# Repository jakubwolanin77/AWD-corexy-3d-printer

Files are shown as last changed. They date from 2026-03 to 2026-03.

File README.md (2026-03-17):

# CoreXY 3D Printer — Engineering Thesis Project






> Engineering Bachelor's Thesis — Jakub Wolanin, 2026  
> Institute of Technology, Automation & Robotics — Industrial Automation  

## 📖 Overview

This repository contains the complete engineering documentation and source files for a custom-built high-speed CoreXY 3D printer designed from scratch. The project covers the full engineering process — from mechanical design verified by FEM simulation, through electrical system integration, to advanced firmware configuration and AI-assisted print monitoring.

The printer is built on open-source solutions (Klipper, Mainsail, Moonraker)



## ✨ Key Features

| Feature | Details |
|---|---|
| 🏗️ Kinematics | CoreXY with 4-motor AWD (All-Wheel Drive) — doubled torque & belt stability |
| 📐 Build Volume | 300 × 265 × 270 mm (X × Y × Z) *(see known issues — belt path limits full 310×310 bed usage)* |
| ⚙️ Frame | 2020 aluminum V-slot profiles — FEM-verified (FreeCAD CalculiX) |
| 🔧 Linear Motion | MGN15 linear rails on all axes |
| 🎯 Auto Leveling | Z-Tilt with KlickyNG magnetic probe — 0.0075 mm accuracy |
| 📳 Resonance Comp. | Input Shaper (ADXL345 accelerometer) — eliminates ringing artifacts |
| 🤖 AI Monitoring |Octoeverywhere — real-time failure detection via camera |
| 📡 Remote Access | Mainsail web UI + ZeroTier Mesh VPN — worldwide monitoring |
| 🔔 Notification* | Discord alerts on print failures |
| 💻 Firmware | [Klipper](https://www.klipper3d.org/) on Raspberry Pi 4 + BTT Octopus Pro |

## 🔬 Mechanical Design Highlights

### Frame — FEM Analysis (FreeCAD + CalculiX)
The frame (530×530×620 mm, 2020 Al profiles) was verified with modal FEM analysis:

| Profile | Resonance freq. Y-axis | Resonance freq. X-axis |
|---|---|---|
| 2020 Al | 33.4 Hz | 35.6 Hz |
FEM modal analysis of the frame X axis
FEM modal analysis of the frame Y axis

**verification via input shaper**
input shaper results X axis
input shaper results Y axis

 Belt System
- GT2 9mm wide belts 
- Fiberglass-reinforced core 
- Non-crossed belt layout — reduced mechanical wear
- Optimal tension range: 45–55 Hz (calculated from string vibration model)

### Printhead: Dragon Burner V8
- Mounted on MGN15 rail ( too heavy, MGN9H should have been used)
- Phaetus Dragon HF hotend (High Flow)
- Sherpa Mini direct drive extruder
- Dual-fan part cooling optimized for high flow rates
- KlickyNG used as probe
---

## ⚠️ Known Issues — Hardware Revision in Progress

The current prototype revealed two mechanical design flaws that are actively being addressed:

### 1. Incorrect Motor Mount & Front-Right Idler Misalignment
- **Issue:** The front-right motor bracket is too weak causing ringing of the belt idler roller. This introduces asymmetric belt tension between the two CoreXY loops.
- **Effect:** Increased ringing artifacts on one print axis that cannot be fully compensated by Input Shaper alone.
- **Status:** 🔧 Redesigning the motor mount bracket — corrected version being modeled in FreeCAD.

### 2. Gantry Mass — Speed Limitation

Gantry

- **Issue:** The current gantry (Dragon Burner V8 toolhead + mounting hardware + dual belts) exceeds the target mass budget, limiting achievable accelerations without introducing resonance beyond the Input Shaper's compensation range.
- **Effect:** Maximum practical print speed is below the original design target.
- **Status:** 🔧 Investigating lighter mounting hardware( carbon fiber square tube + MGN9H linear rail) and alternative toolhead configurations to reduce moving mass.

### 3. XY Axis Design — Reduced Effective Build Volume
- **Issue:** The current XY belt routing geometry places the belt path in a way that physically interferes with the printhead's range of motion on one side. The physical bed is 310×310 mm, but the usable print area is limited to **300×265 mm** because the belt blocks the toolhead from reaching the full bed surface.
- **Effect:** ~15% of the heated bed area is inaccessible — wasted heating energy and reduced print area.
- **Status:** 🔧 XY belt routing needs to be redesigned with additional clearance; corrected idler positions being evaluated.

### 4. Heated Bed — Insufficient Power & Slow Heat-Up
- **Issue:** The installed heated bed has insufficient wattage for the 310×310 mm surface area, resulting in very slow heat-up times and difficulty maintaining uniform temperature across the bed, especially at corners.
- **Effect:** Long wait times before printing; possible temperature gradients causing adhesion issues near bed edges.
- **Status:** 🔧 Evaluating higher-wattage bed heater or AC mains bed (via SSR relay) as a replacement.

### 5. Bed Z-Stability — 3-Point Mount Sagging (~0.2 mm First Layer Variation)

heightmap of the heated bed

- **Issue:** The heated bed is attached to the Z-axis using a 3-point mounting system. To adapt from the bed's 2-hole pattern to the 3-point lead screw layout, a bridge/adapter beam was used. This introduces structural flex — the bed sags between support points, causing a measurable height variation of approximately **0.2 mm** across the first layer, visible in bed mesh scans.
- **Effect:** First layer consistency is compromised; mesh compensation partially corrects this, but the flex remains a source of instability.
- **Status:** 🔧 A 4-point mounting design (direct attachment without adapter beam) is being developed to eliminate the flex and improve Z-plane rigidity.

> 📸 *Bed mesh scan photo documenting the Z variation will be added to the `assets/` directory.*

---

## 📁 Repository Structure

```
AWD-corexy-3d-printer/
├── README.md
├── LICENSE                              # GPL-3.0
│
├── CAD/                                 # Custom-designed components (STEP format)
│   ├── XY motor front right mounting.step
│   ├── XY motor front-left mounting.step
│   ├── XY motor rear-left mounting.step
│   ├── XY motor rear-right mounting.step
│   ├── Z motor left mounting.step
│   ├── Z motor rear mounting.step
│   ├── Z motor right mounting.step
│   ├── endstop X mounting.step
│   ├── gantry mounting left.step
│   ├── gantry mounting right.step
│   ├── heated bed mounting back.step
│   ├── heated bed mounting left.step
│   ├── heated bed mounting right.step
│   ├── klickyNG dock mounting.step
│   ├── printhead mounting1.step
│   └── printhead mounting2.step
│
├── conf files/                          # Real Klipper configuration files
│   ├── printer.cfg                      # Main Klipper config (BTT Octopus Pro, CoreXY AWD)
│   ├── mainsail.cfg                     # Mainsail UI configuration
│   ├── moonraker.conf.txt               # Moonraker API server config
│   ├── octoeverywhere.conf.txt          # OctoEverywhere remote access config
│   └── crowsnest.conf                   # Camera streaming config
│
└── documentation/                       # Engineering documentation & schematics
    ├── Jakub Wolanin-praca inż.pdf      # Full engineering thesis (Polish)
    ├── Załącznik 1 Schemat połączeń elektrycznych  # Wiring schematic
    ├── schemat sterowanie i komunikacja            # Control & communication diagram
    └── schemat zasilanie.png            # Power supply schematic
```

---

## 🚀 Quick Start — Klipper Config

All configuration files are in [`klipper_config/`](./klipper_config/).

> ⚠️ **Important:** Pin assignments in `printer.cfg` are specific to the **BTT Octopus Pro** board with the motor layout described in the thesis. Adjust per your hardware.

## 🛠️ Technologies Used

- **Firmware:** [Klipper](https://www.klipper3d.org/) + [Moonraker](https://github.com/Arksine/moonraker)
- **Printer Control (AI):** [OctoPrint](https://octoprint.org/)
- **Web UI:** [Mainsail](https://docs.mainsail.xyz/)
- **Camera:** Crowsnest stream server
- **VPN:** ZeroTier Mesh VPN
- **FEM Analysis:** FreeCAD + CalculiX solver
- **CAD:** FreeCAD
- **MCU:** BTT Octopus Pro (STM32F429)
- **Host:** Raspberry Pi 4

---

## 📜 License & Open-Source Credits

This project is released under the **[GPL-3.0 License](./LICENSE)**.

It builds upon the following open-source projects:

| Project | License | Repository |
|---|---|---|
| Klipper | GPL-3.0 | [github.com/Klipper3d/klipper](https://github.com/Klipper3d/klipper) |
| Moonraker | GPL-3.0 | [github.com/Arksine/moonraker](https://github.com/Arksine/moonraker) |
| Mainsail | GPL-3.0 | [github.com/mainsail-crew/mainsail](https://github.com/mainsail-crew/mainsail) |
| Dragon Burner V8 | GPL-3.0 | [github.com/chirpy2605/voron-user-mods](https://github.com/chirpy2605/voron-user-mods) |
| Sherpa Mini Extruder | GPL-3.0 | [github.com/Annex-Engineering/Sherpa_Mini-Extruder](https://github.com/Annex-Engineering/Sherpa_Mini-Extruder) |
| KlickyNG Probe | GPL-3.0 | [github.com/jlas1/Klicky-Probe](https://github.com/jlas1/Klicky-Probe) |
| OctoPrint | AGPL-3.0 | [github.com/OctoPrint/OctoPrint](https://github.com/OctoPrint/OctoPrint) |

All original design work, configuration, documentation and code in this repository is © 2026 Jakub Wolanin and licensed under GPL-3.0.

---

## 👤 Author

**Jakub Wolanin**  
Engineering thesis — Automation & Robotics, Industrial Automation specialization  
Krosno 2026
contact:
jakubwolanin77@gmail.com

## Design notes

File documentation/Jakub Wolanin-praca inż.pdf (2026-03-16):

INSTYTUT | Politechniczny
KIERUNEK: | Automatyka i Robotyka
KSZTAŁCENIE W ZAKRESIE: | Automatyka przemysłowa

## Jakub Wolanin

27111

## Projekt drukarki 3D

### Praca dyplomowa inżynierska napisana pod kierunkiem:

dr hab. inż., Tomasz
Korbiel

## Przyjmuję pracę: |

(data i podpis promotora)

## Krosno 2025

Spis Treści

### Spis treści

Załącznik nr 1 -Schemat połączeń elektrycznych systemu sterowania drukarką 3D ... 125

1.Wprowadzenie

### 1.1 Cel pracy

Celem niniejszej pracy inżynierskiej jest opracowanie kompletnej dokumentacji inżynierskiej i produkcyjnej drukarki 3D typu CoreXY.

Projekt obejmuje nie tylko założenia konstrukcyjne fizycznego urządzenia (ramy nośnej, układu napędowego), ale również – jako integralną część zadania inżynierskiego – dobór i wdrożenie zaawansowanych algorytmów sterowania w środowisku Klipper. Algorytmy te obejmują kompensację drgań Input Shaper oraz sterowanie wyprzedzające - Pressure Advance.

Cel pracy zostaje osiągnięty poprzez stworzenie projektu gotowego do wdrożenia (prototypowania). Fizyczna budowa i uruchomienie prototypu, opisane w dalszej części pracy, stanowią etap weryfikacyjny przyjętych założeń projektowych, potwierdzający poprawność przygotowanej dokumentacji.

### 1.2 Zakres i wymagania funkcjonalne projektu

Zakres niniejszego projektu obejmuje zaprojektowanie, wykonanie, kalibrację oraz

uruchomienie drukarki 3D typu CoreXY opartej na oprogramowaniu Klipper i

rozwiązaniach open-source. Urządzenie ma łączyć wysoką jakość wydruku z wysoką

prędkością.

Szczegółowy zakres projektu:

1. Analiza wstępna - przegląd istniejących rozwiązań w dziedzinie drukarek 3D

FDM oraz wybór odpowiedniej kinematyki jako podstawy konstrukcji

2. Projekt mechaniczny drukarki obejmujący:
- opracowanie konstrukcji ramy o wysokiej sztywności,
- zaprojektowanie układu napędowego dla osi X/Y/Z,
3. Projekt elektryczny drukarki obejmujący dobór oraz integrację komponentów

takich jak:

- płyta główna,
- silniki krokowe i sterowniki,
- czujniki,
- zasilacz,
- odpowiednie przewody.
4. Konfiguracja oprogramowania Klipper oraz kalibracja drukarki 3D

Wymagania funkcjonalne drukarki 3D:

Projektowana drukarka powinna spełniać następujące wymagania funkcjonalne:

- Konstrukcja pozwalająca na obszar roboczy minimum 300x265x280mm (X, Y,

Z).

- Sztywna rama zapewniająca minimalne drgania i odkształcenia
- Zastosowanie lekkiej, sztywnej głowicy pozwalającej na druk z dużymi

prędkościami.

- Automatyczne poziomowanie stołu roboczego (procedura Z-Tilt z sondą

KlickyNG)

- Kontrola temperatury stołu roboczego.

Kontrola temperatury głowicy.

- Czujnik obecności filamentu.
- Analiza drgań w celu eliminacji rezonansów (akcelerometr + Input Shaper).
- Kontrola chłodzenia wydruku.
- Możliwość druku wielu materiałów takich jak: PETG, PLA, TPU.
- Łatwość rozbudowy dzięki modularnej budowie.
- Wysoka powtarzalność i stabilność wydruków.
- Inspekcja procesu przy użyciu AI (model YOLOv8)
- Zdalne sterowanie i monitoring (interfejs Mainsail + VPN)

### 2. Teoria druku FFF

### 2.1 Podstawy technologii FFF

Technologia FFF (Fused Filament Fabrication) – to jedna z technologii wytwarzania przyrostowego, w której element powstaje poprzez warstwowe nakładanie uplastycznionego tworzywa termoplastycznego [2]. Materiał w postaci filamentu jest wprowadzany do podgrzewanej głowicy, gdzie zostaje stopiony i następnie wyciskany przez dyszę wzdłuż zaprogramowanej ścieżki. W ten sposób kolejne warstwy łączą się ze sobą, tworząc gotowy model

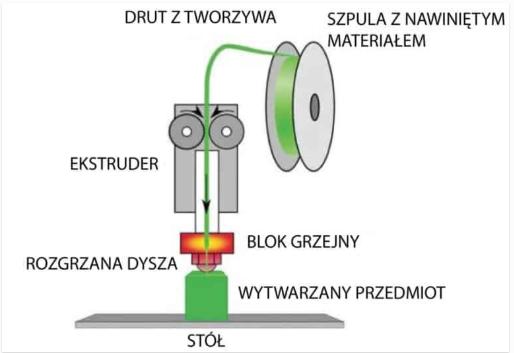
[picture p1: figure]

Rys. 1. Schemat procesu technologii FFF. Źródło: [1].

Technologia FFF ma pewne ograniczenia takie jak:
- widoczność linii warstw,
- trudność w druku nagłych zwisów (>55°)
- mniejsza dokładność wymiarowa niż w innych metodach druku 3D tj. SLA czy SLS, ze względu na kurczliwość materiału podczas chłodzenia

### 2.2 Parametry wpływające na jakość i prędkość druku

Ostateczna jakość i czas wydruku zależą od dużej liczby parametrów procesowych. Odpowiednie dobranie parametrów jest kluczowe dla uzyskania stabilności wymiarowej, wytrzymałości oraz jakości powierzchni wydruku.

Najważniejsze parametry wpływające na końcowy produkt:

Grubość warstwy
Mniejsza grubość warstwy poprawia adhezję warstw oraz jakość powierzchni wydruku. Jednocześnie znacząco wydłuża czas druku. Zwiększenie grubości warstwy pozwala skrócić czas wydruku kosztem jakości oraz adhezji warstw w osi Z.

Rys. 2. Porównanie czasu wydruku w zależności od grubości warstwy. Źródło: [4].

Rys. 3. Porównanie jakości powierzchni w zależności od grubości warstwy. Źródło: [4].

Temperatura dyszy
Temperatura wpływa na lepkość materiału oraz jakość łączenia warstw.

Zbyt niska temperatura powoduje:
- niedostateczne uplastycznienie filamentu,
- słabe sklejenie warstw,
- chropowatą powierzchnię,
- możliwe zatory,
- zwiększenie ryzyka pękania. Zbyt wysoka temperatura powoduje:
- zbytnie upłynnienie filamentu,
- rozmyte szczegóły,
- widoczne przebarwienia,
- zjawisko nitkowania.

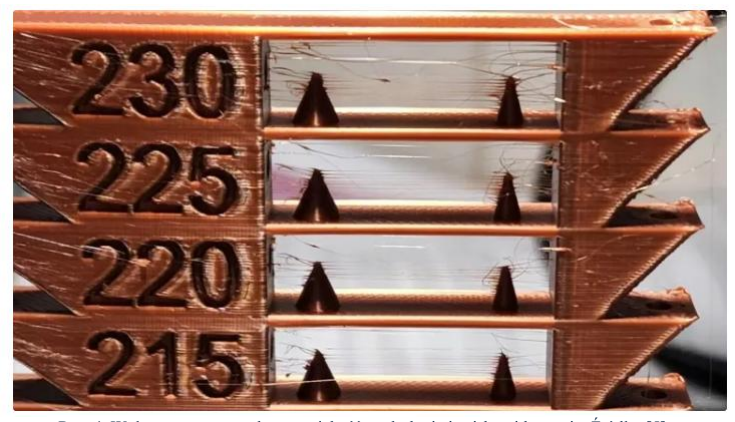
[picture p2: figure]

Rys. 4. Wpływ temperatury dyszy na jakość wydruku i zjawisko nitkowania. Źródło: [5].

Temperatura stołu
- Zbyt niska temperatura stołu powoduje słabe przywieranie modelu do stołu. Model może podwijać się w rogach oraz deformować ze względu na nierównomierne stygnięcie wydruku.
- Zbyt wysoka temperatura może prowadzić do wybrzuszeń lub pofalowania warstw z powodu nadmiernego rozszerzenia się filamentu.

Rys.5 Podwijanie się wydruku. Źródło: [6]

Chłodzenie
Prędkość wentylatora chłodzącego wydruk. Chłodzenie jest niezbędne do szybkiego utwardzania materiału, co pozwala na druk mostów i zwisów bez konieczności stosowania podpór na krótkich odcinkach. Przy wydruku z takich materiałów jak ABS chłodzenie musi być wyłączone. Gwałtowne utwardzenie materiału prowadzi do deformacji wydruku i osłabienia wiązań międzywarstwowych.

Prędkość druku
Zwiększenie prędkości znacząco skraca czas wydruku, jednak może pogorszyć jakość powierzchni i powodować gorsze połączenie warstw. Prędkość wydruku należy dobierać zależnie od konstrukcji drukarki oraz jej podzespołów. Sztywniejsza konstrukcja oraz większa przepustowość hotendu pozwalają uzyskać większe prędkości druku bez pogarszania jego jakości.

Liczba obrysów
Jest to liczba linii osadzanych na zewnątrz i wewnątrz ścian modelu. Oznacza to grubość solidnej ściany modelu. Większa liczba obrysów zwiększa sztywność i odporność na pękanie. Zwiększenie liczby obrysów wydłuża czas druku.

Rys. 6. Wpływ liczby obrysów na strukturę ściany modelu. Źródło: [7].

Projektując model w środowisku CAD, należy grubość cienkiej ścianki dobrać tak, aby obliczona przez slicer optymalna grubość odpowiadała założonej liczbie obrysów i wysokości warstwy. Pozwala to uzyskać najlepszą jakość powierzchni ścian, unikając nakładania się obrysów.
Przykładowo PrusaSlicer, do obliczania optymalnej grubości cienkiej ściany używa konkretnego wzoru.

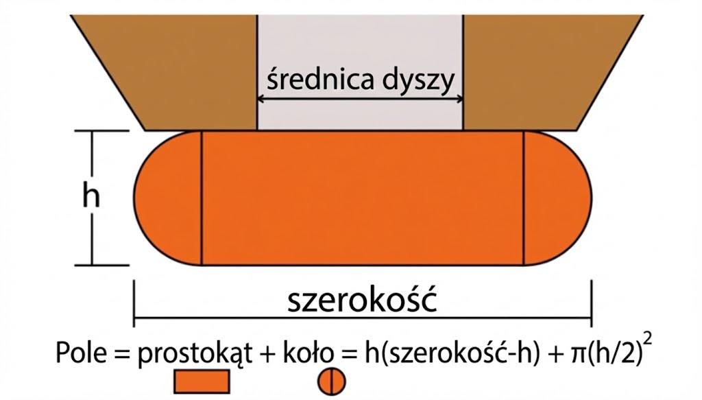
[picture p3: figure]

Rys. 7.Wzór obliczania optymalnej szerokości ścieżki (grubości ścianki). Źródło: [7].

Zwarte warstwy górne/dolne
Zwiększenie liczby warstw dolnych lub górnych zwiększa grubość podstawy lub powłoki górnej. Im większa liczba zwartych warstw, tym większa wytrzymałość oraz sztywność modelu. Zwiększenie liczby zwartych warstw wydłuża wydruk.

Rys. 8. Wpływ liczby górnych warstw na jakość zamknięcia powierzchni (od lewej: 1, 2, 3, 5 warstw). Źródło: [8].

Wypełnienie
Gęstość wewnętrznej struktury wypełniającej model, wyrażana w procentach. Im większa gęstość wypełnienia, tym większa wytrzymałość i waga modelu.

Rys. 9. Zależność między gęstością wypełnienia a parametrami wytrzymałościowymi i czasem druku.
Źródło: [8].

Wzór wypełnienia
Geometria siatki wypełnienia. Opcji wzoru siatki jest wiele i należy ją dobrać indywidualnie do danego modelu. Wzór siatki wpływa znacząco na wytrzymałość i czas wydruku.
Wybierając wzór typu Gyroid zapewniamy niemalże jednakową wytrzymałość we wszystkich kierunkach. Wybierając wzór typu Cubic najlepszą wytrzymałość uzyskamy wzdłuż osi Z.

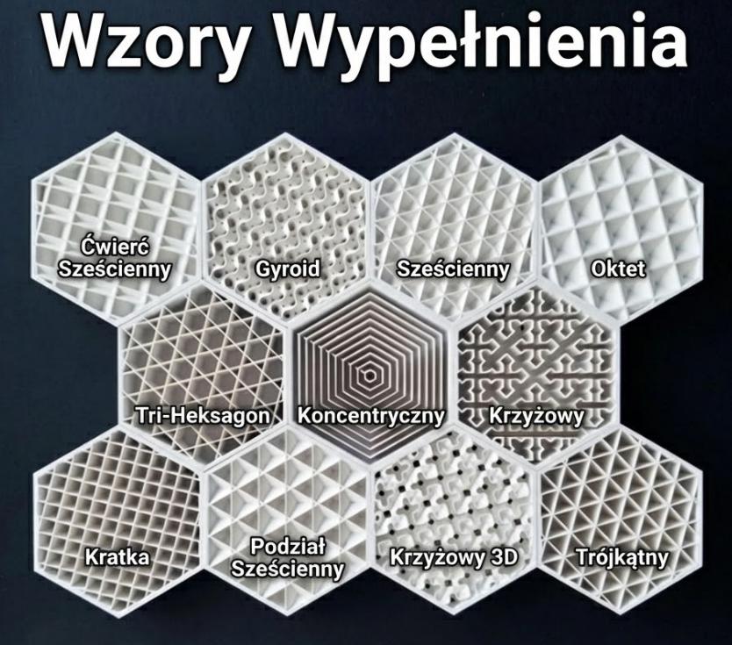
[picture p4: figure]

Rys. 10. Przykłady wzorów wypełnienia stosowanych w druku 3D. Źródło: [9].

Retrakcja
Szybkość oraz długość cofnięcia filamentu przez ekstruder w głowicy. Niepoprawnie skalibrowana retrakcja powoduje wyciekanie materiału z dyszy, czego skutkiem jest nitkowanie.

### 2.3 Typy kinematyki drukarek -porównanie

Kinematyka drukarki to sposób, w jaki ruch obrotowy silników przekłada się na ruch głowicy i stołu roboczego w przestrzeni trójwymiarowej [12]. Wybór architektury ma kluczowy wpływ na sztywność i precyzję drukarki 3D.

Kinematyka Kartezjańska:
Jest to najbardziej rozpowszechniony typ, szczególnie w tańszych i hobbystycznych drukarkach.
Zasada działania
- Oś X – porusza głowicą drukującą (lewo-prawo)
- Oś Y – porusza stołem roboczym (przód- tył)
- Oś Z- porusza osią X (góra-dół)

Rys. 11. Drukarka Creality Ender 3 S1 Pro jako przykład kinematyki kartezjańskiej ("Bedslinger"). Źródło:[34]

Zalety:
- Prostota konstrukcji
- Niska cena,
- niezależność ruchu osi ułatwia kalibrację i rozwiązywanie problemów.

Wady:
- Niska prędkość ograniczona ciężkim stołem roboczym.

Kinematyka CoreXY:
Architektura ta popularna jest w zaawansowanych konstrukcjach DIY oraz droższych drukarkach do zastosowań profesjonalnych.

Zasada działania:
- Oś Z: Stół porusza się tylko w pionie
- Oś X/Y: Głowica porusza w płaszczyźnie poziomej, napędzana przez układ dwóch lub czterech stacjonarnych silników i system pasków. Ruch w osi X wymaga zgodnego obrotu silników, a ruch w osi Y- przeciwbieżnego [12].

Rys. 12. Drukarka Sovol SV08 jako przykład kinematyki CoreXY. Źródło: [35].

Zalety:
- Większa sztywność całej konstrukcji
- Silniki pozostają nieruchome na ramie, co znacząco obniża masę głowicy
- Wyższa prędkość oraz przyspieszenie
Wady:
- Złożony układ pasków napędowych
- Wymaga precyzyjnego naciągnięcia i prowadzenia
- Błędy konstrukcyjne lub montażowe mają przełożenie na obie osie (X i Y)

Kinematyka Delta:
Konstrukcja typu Delta jest najrzadziej spotykanym typem kinematyki w komercyjnych drukarkach 3D, zazwyczaj dominuje ona w segmentach, w których liczy się szybkość i wysokość wydruku.

Zasada działania
Głowica zawieszona jest na 3 ramionach i poruszana przez 3 silniki umieszczone na górze ramy. Głowica porusza się w 3 osiach (X, Y, Z). Pozycja głowicy jest obliczana poprzez złożoną geometrię na podstawie długości ramion i ruchu silników.

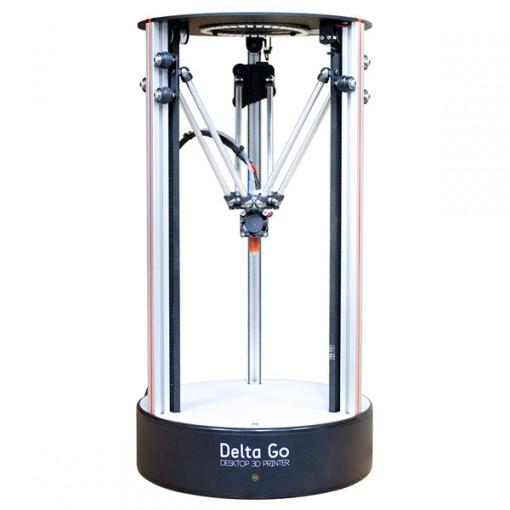
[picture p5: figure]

Rys. 13. Drukarka Deltaprintr Delta Go jako przykład kinematyki Delta. Źródło [36].

Zalety:
- Bardzo lekka głowica i nieruchomy stół pozwalają na uzyskanie bardzo dużych prędkości wydruku.
Wady:
- Sposób konstrukcji wymusza zastosowanie cylindrycznej przestrzeni roboczej, co znacznie ją pomniejsza w porównaniu do innych typów kinematyki
- Próbując powiększyć dostępną przestrzeń roboczą, zmuszeni jesteśmy wydłużać ramiona, które mogą wpadać w wibracje powodujące artefakty na końcowym wydruku

### 3. Projekt mechaniczny drukarki

### 3.1 Wprowadzenie

Konstrukcja mechaniczna jest kluczowym elementem budowy drukarki 3D. Wpływa zarówno na sposób działania urządzenia, jak i na możliwości jego modernizacji w przyszłości.

W przypadku drukarek wykorzystujących kinematykę CoreXY, szczególnie ważne jest skupienie się na sztywności ramy, dokładności prowadzenia osi oraz zachowaniu jak najmniejszej masy części ruchomych. Konstrukcja mechaniczna powinna zapewniać stabilność drukarki przy dużych prędkościach, redukować wibracje i umożliwiać dokładne odwzorowanie kształtu modelu.

### 3.2 Rama nośna

Geometria i materiał

Rys. 14. Projekt ramy drukarki CoreXY.

Legenda:
- 1-4 – Profile aluminiowe V-slot 2020 620mm
- 5 - Profil aluminiowy V-slot 2020 500mm
- 6-17 - Profile aluminiowe V-slot 2020 490mm

Główna rama drukarki to podstawa całego systemu CoreXY, zaprojektowana została jako prostopadłościan o wymiarach 530x530x620 wykonany z profili aluminiowych 2020.

Uzasadnienie wyboru materiału:
Wybór profilu 2020 został poprzedzony analizą alternatywnych rozwiązań z uwzględnieniem specyfiki systemu CoreXY [12]. System ten wymaga minimalizacji masy ruchomej i maksymalizacji sztywności ramy stałej w celu skutecznego tłumienia rezonansów przy dużych przyspieszeniach.

1 Rama spawana z profili stalowych - Zapewnia wysoką sztywność, jednak proces spawania wprowadza naprężenia cieplne i wymaga zachowania idealnej prostopadłości. Każda odchyłka trwale obniża jakość druku, a konstrukcja jest niemodyfikowalna.
2 Rama skręcana z profili aluminiowych V-slot - Modułowość pozwala na łatwe modyfikacje (np. powiększenie pola roboczego przez wymianę profili pionowych). Jest to standard w konstrukcjach amatorskich i półprofesjonalnych.

Dobór profilu ramy:

Tab.1. Porównanie parametrów profili aluminiowych V-slot. Źródło: [15], [16].
Parametr | Profil aluminiowy 2020 | Profil aluminiowy 3030
Moment bezwładności Ix | 6531,00 [mm⁴ ] | 26797,00 [mm⁴ ]
Waga nominalna | 0,429 [kg/m] | 0.835[kg/m]
Cena za 1mb | 22,66 [zł] | 42,10 [zł

W celu weryfikacji doboru profilu nośnego przeprowadzono obliczenia statycznego ugięcia belki dla zastosowanego profilu 2020 oraz alternatywnego profilu 3030.

Wzór na strzałkę ugięcia belki swobodnie podpartej:

f =

F ∗ L

3
48 ∗ E ∗ Ix

Wzór na strzałkę ugięcia belki obustronnie utwierdzonej:

f =

F ∗ L

3
192 ∗ E ∗ Ix

Do obliczeń przyjęto następujące wartości:
- Materiał: Aluminium 6063-T5 (Moduł Younga E = 69 GPa)
- Długość belki L = 490 mm
- Obciążenie punktowe F = 10.0 N (połowa masy całej osi bramowej)
- Moment bezwładności Ix 6531 mm⁴

Analiza dla ramy nośnej (Oś Y- profile nr 11 i 13):

### 1. Belka swobodnie podparta profil 2020:

f2020 =

10 ∗ 490³
48 ∗ 69000 ∗ 6531 ≈ 0,0544mm

Rys. 15. Analiza ugięcia profilu 2020 – belka swobodnie podparta (obustronnie). Źródło:[16]

### 2. Belka utwierdzona obustronnie profil 2020:

f2020 =

10 ∗ 490³
192 ∗ 69000 ∗ 6531 ≈ 0,0136mm

Rys. 16. Analiza ugięcia profilu 2020 – belka utwierdzona obustronnie. Źródło:[16]

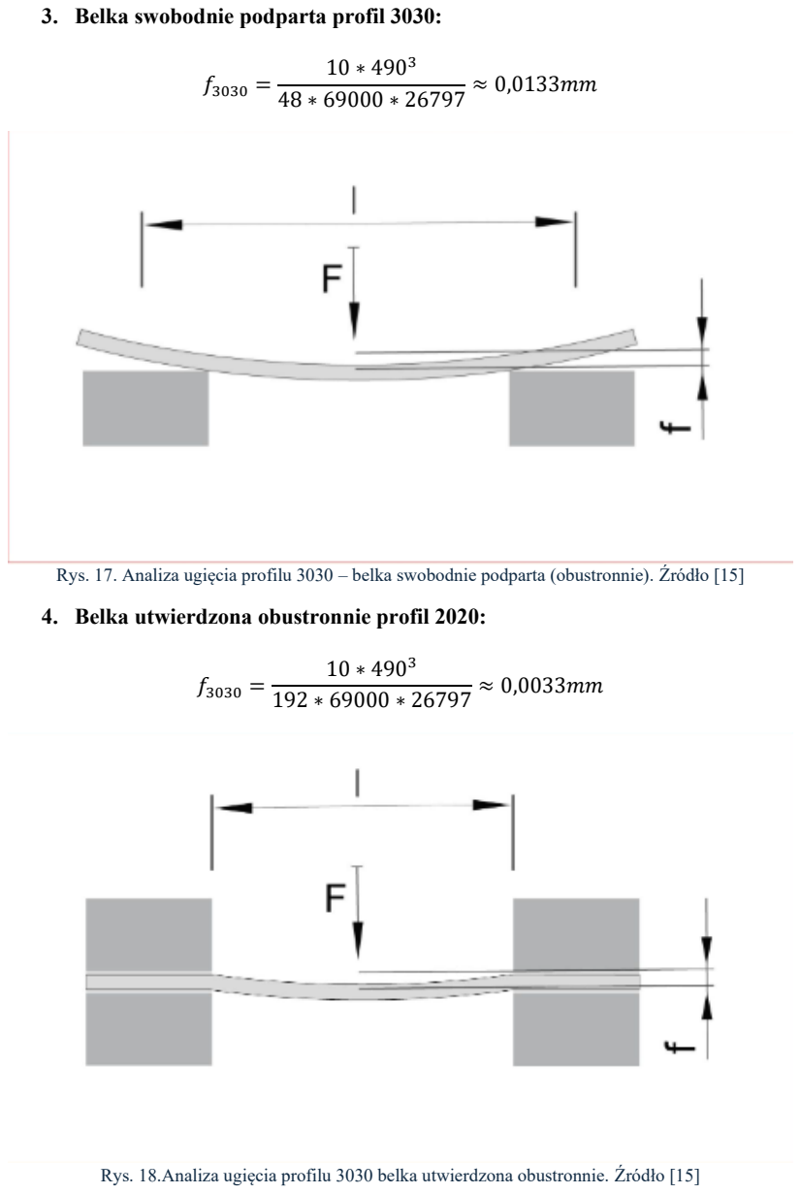
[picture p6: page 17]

### 3. Belka swobodnie podparta profil 3030:

f3030 =

10 ∗ 490³
48 ∗ 69000 ∗ 26797 ≈ 0,0133mm

Rys. 17. Analiza ugięcia profilu 3030 – belka swobodnie podparta (obustronnie). Źródło [15]

### 4. Belka utwierdzona obustronnie profil 2020:

f3030 =

10 ∗ 490³
192 ∗ 69000 ∗ 26797 ≈ 0,0033mm

Rys. 18.Analiza ugięcia profilu 3030 belka utwierdzona obustronnie. Źródło [15]

Wnioski:
Z uwagi na zastosowanie w projekcie sztywnych połączeń narożnych (kątowniki aluminiowe oraz płyty węzłowe), rzeczywista praca konstrukcji odpowiada modelowi belki utwierdzonej obustronnie.

W tym wariancie ugięcie statyczne dla profilu 2020 wynosi 0,013 mm, natomiast dla profilu 3030 wynosi 0,0033 mm. Różnica pomiędzy tymi wartościami wynosi zaledwie 0,010 mm.

W technologii druku FDM, gdzie standardowa wysokość warstwy wynosi 0,2 mm, różnica ta jest całkowicie pomijalna. Nie ma mierzalnego wpływu na geometrię układanych warstw. Oznacza to, że z punktu widzenia sztywności statycznej zastosowanie cięższego i droższego profilu 3030 nie przynosi wymiernych korzyści dla jakości wydruku. Profil 2020 okazuje się optymalnym wyborem.

Geometria zamknięta i stabilność termiczna:
Przyjęcie zamkniętej geometrii prostopadłościanu jest kluczowe dla integralności strukturalnej systemu CoreXY. Taka konstrukcja zapewnia maksymalną odporność na skręcanie i zginanie ramy, co jest warunkiem wstępnym dla osiągnięcia wysokiej precyzji i pozycjonowania. Dodatkowo zamknięta struktura tworzy bazę dla komory grzewczej, która kluczowa jest do skutecznego drukowania materiałów o wysokim skurczu termicznym, takich jak ABS czy ASA.

Analiza modalna ramy – MES:
Ponieważ analiza statyczna wykazała pomijalne różnice w ugięciach, kluczowym kryterium wyboru profilu stała się dynamika. W celu weryfikacji zachowania ramy przy wysokich przyspieszeniach, przeprowadzono analizę modalną (częstotliwości drgań własnych) w środowisku FreeCAD (moduł FEM).

Metodyka badania:
Przedmiotem symulacji był uproszczony model ramy obciążony masą karetki:
- Model: Profile 2020 połączone sztywno.
- Masa: Dodano masę skupioną na środku belki X, reprezentującą głowicę w najgorszym położeniu.
- Solver: CalculiX (Frequency Analysis), poszukiwanie 10 pierwszych postaci drgań.

Wyniki symulacji profil 2020:
Zidentyfikowano kluczowe postacie drgań wpływające na jakość wydruku
Rys. 19 Wizualizacja drgań własnych dla ramy z profilu 2020 w osi Y | Rys. 20 Wizualizacja drgań własnych dla ramy z profilu 2020 w osi X

Wyniki symulacji profil 3030:
W celu pełnej weryfikacji decyzji projektowej, przeprowadzono analogiczną symulację dla ramy wykonanej z cięższych profili 3030.
Rys. 21 Wizualizacja drgań własnych dla ramy z profilu 3030 w osi Y | Rys. 22 Wizualizacja drgań własnych dla ramy z profilu 2020 w osi Y

Interpretacja wyników:
Wartości przemieszczeń w analizie modalnej są znormalizowane i obrazują jedynie postać (kształt) drgań, a nie ich rzeczywistą amplitudę. Kluczowym wynikiem jest częstotliwość występowania rezonansu.

Tab.2 Porównanie wyników analizy MES
Parametr | Profil 2020 | Profil 3030 | Zmiana
Częstotliwość drgań (Oś Y) [Hz] | 33,4 | 53,15 | +59%
Częstotliwość drgań (Oś X) [Hz] | 35,6 | 56,80 | +60%

Wnioski końcowe:
Symulacja wykazała, że zastosowanie profili 3030 zwiększyłoby częstotliwości rezonansowe konstrukcji do poziomu ~55 Hz. Jest to wynik lepszy, jednakże uzyskany kosztem podwojenia masy ramy nośnej i znacznego wzrostu kosztów budowy.

Wartości uzyskane dla profilu 2020 (powyżej 30 Hz) mieszczą się w standardzie akceptowalnym dla drukarek tej klasy i tego rozmiaru. Częstotliwości rzędu 33-35 Hz mogą być skutecznie kompensowane przez algorytm Input Shaper bez drastycznego ograniczania przyspieszeń

Z tego powodu uznano, że profil 2020 stanowi optymalny kompromis zapewniający wystarczającą sztywność przy minimalizacji kosztów i masy urządzenia. Decyzja ta została pozytywnie zweryfikowana podczas testów wydruku (Rozdział 6).

Węzły połączeniowe

Czynnikiem decydującym o rzeczywistej sztywności ramy są jej połączenia narożne:

- Kątowniki zewnętrzne – montowane na zewnątrz pozwalające na uzyskanie bardzo dużej sztywności konstrukcji, mogą kolidować z panelami obudowy.
- Kątowniki wewnętrzne – ukryte w rowkach profili, mocowane śrubami wchodzącymi w otwory końcowe, dzięki mocowaniu w rowkach profili nie kolidują z innymi elementami, minusem jest jednak mniejsza siła zacisku i sztywność niż kątowniki zewnętrzne.
- Wewnętrzne łączniki wciskane – metalowy łącznik wkładany do rowka profilu mocowany śrubą rozprężną. Wadą jest niska sztywność skrętna w połączeniach narożnych.
•
Ze względu na wysoką sztywność oraz łatwość montażu projekt wykorzystuje kątowniki zewnętrzne do połączeń narożnych. Kątowniki przykręcane są do profili za pomocą śrub M5 oraz V-nakrętek.

### 3.3 Układ ruchu osi X/Y oraz kinematyka CoreXY

W projekcie zastosowano kinematykę CoreXY. W tej konfiguracji ruch głowicy w osiach X oraz Y realizowany jest poprzez współbieżną pracę dwóch niezależnych pętli pasów napędowych GT2.

W klasycznej konfiguracji stosuje się dwa silniki. W niniejszej konstrukcji wykorzystano cztery silniki – po dwa na każdą pętlę. Pozwala to zwiększyć moment napędowy, obniżyć obciążenie pojedynczego silnika oraz poprawić stabilność naciągu pasków przy wysokich prędkościach

W kontekście drukarek 3D typu CoreXY, za ruch w osi X/Y odpowiada tzw. oś bramowa – jest to cały zespół ruchomy który przemieszcza głowicę drukującą w płaszczyźnie poziomej (osie X i Y)

Rys. 23. Wizualizacja kompletnej osi bramowej (X/Y) użytej w projekcie.

Równania ruchu (Kinematyka)
W układzie CoreXY żaden silnik nie odpowiada za jedną, pojedynczą oś. Przemieszczenie głowicy wynika z różnicowej lub sumarycznej pracy napędów [12]:

∆X =

1
2

(∆LA + ∆LB)

∆Y =

1
2

(∆LA − ∆LB)
gdzie:
∆X, ∆Y – przemieszczenie w osiach X i Y
∆LA, ∆LB – Zmiana długości pasów (ruch silników A i B)

W zastosowanej konfiguracji z napędem z czterema silnikami, dwa silniki pracują równolegle na pętlę, więc wartości ∆LAi ∆LB są sumarycznym efektem pracy odpowiednich par silników:

∆LA = ∆LA1 + ∆LA2
∆LB = ∆LB1 + ∆LB2

System prowadzenia liniowego
System prowadzenia w osiach X/Y jest kluczowy dla stabilności, prędkości oraz precyzji drukarki. We współczesnych drukarkach FFF stosuje się 3 główne typy prowadzenia:
1. Koła V-slot – System oparty na kołach poliwęglanowych które toczą się w rowkach profili aluminiowych.

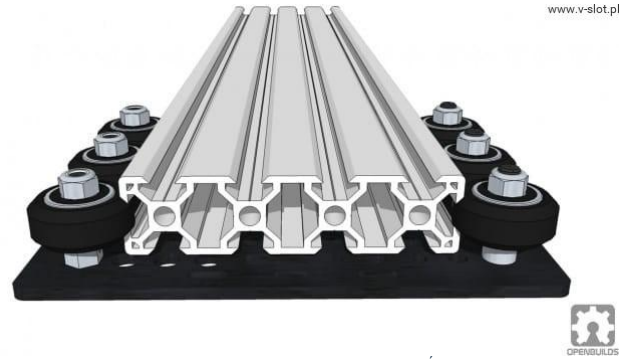
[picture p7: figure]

Rys. 24. System prowadzenia oparty na rolkach V-Slot. Źródło: [37].

Zalety:
- Niski koszt,
- Łatwa instalacja,
- Cicha praca.

Wady:
- Duża podatność na zużycie spowodowane wycieraniem się kół
- Konieczność częstej regulacji.
2. Wałki liniowe – hartowane wałki stalowe (zazwyczaj 8mm lub 10mm) z łożyskami kulkowymi.

Rys. 25. Przykład modułu napędowego opartego na wałkach liniowych. Źródło: [38].

Zalety:
- Nieduży koszt
- Dobra dostępność
- Łatwa wymiana łożysk

Wady:
- Wyższe opory w porównaniu do prowadnic MGN
- Wymagana sztywna konstrukcja ramy, aby zapewnić precyzyjne równoległe prowadzenie wałków

3. Prowadnice liniowe MGN– szyna stalowa z wózkiem zawierającym wiele łożysk kulkowych

Rys. 26. Prowadnica liniowa typu MGN15 z wózkiem łożyskowanym. Źródło: [39].

Zalety:
- Minimalne opory ruchu
- Bardzo wysoka sztywność i precyzja pozycjonowania
- Długa żywotność
Wady:
- Wyższy koszt
- Wrażliwość na zanieczyszczenia

Wybór dla projektu: prowadnice liniowe MGN15
W projekcie zastosowano prowadnice liniowe MGN15 ze względu na najlepsze parametry dynamiczne oraz możliwość osiągania wysokich przyspieszeń bez utraty precyzji pozycjonowania.

Projekt węzłów mocujących
Mocowania osi bramowej stanowią krytyczny interfejs mechaniczny, który łączy profil nośny osi X z wózkami szyn liniowych MGN15 na bocznych profilach ramy. Głównym zadaniem mocowań jest zapewnienie sztywnego i precyzyjnego połączenia między ruchomymi elementami prowadzącymi, a lekkim profilem osi X.
- Integracja kinematyczna – Mocowania muszą posiadać precyzyjnie zdefiniowane punkty mocowania dla paska przenoszącego napęd, tak aby zapewnić mu właściwą geometrię.
- Transmisja obciążeń – Elementy te muszą efektywnie przenosić dynamiczne siły inercyjne generowane podczas gwałtownego przyspieszania i hamowania osi

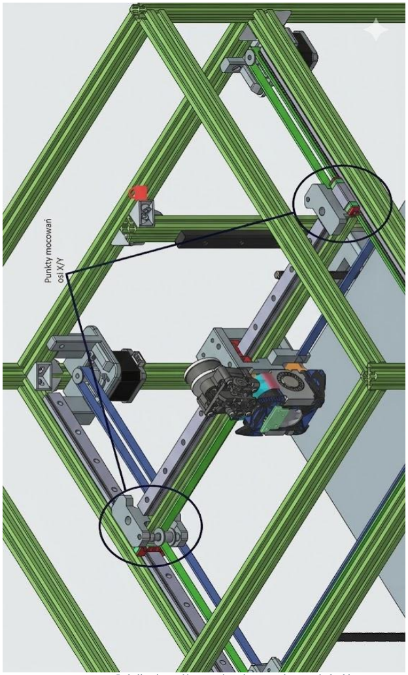
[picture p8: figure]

Rys. 27. Lokalizacja węzłów mocujących w zespole ramy drukarki.

Rys. 28. Rysunek lewego mocowania osi bramowej.

Rys. 29. Model 3D lewego mocowania osi bramowej.

Rys. 30. Rysunek techniczny prawego mocowania osi bramowej.

Rys. 31. Model 3D prawego mocowania osi bramowej.

Technologia wykonania:
Mocowania zaleca się wykonać z aluminium, jednak dopuszczalne jest również druk 3D z materiału ASA/ABS.
Dla maksymalizacji wytrzymałości zaleca się druk z następującymi parametrami:
- Dysza - 0,4mm
- Wysokość pierwszej warstwy – 0,15mm
- Wysokość warstwy – 0,2mm
- Obrysy – 6
- Zwarte warstwy górne/dolne – 7
- Wypełnienie – minimum 70%
- Rodzaj wypełnienia - Gyroid

### 3.4 Pasy napędowe

W celu minimalizacji błędów pozycjonowania dynamicznego zastosowano pasy napędowe GT2 o szerokości 9 mm, wzmocnione włóknem szklanym. Stanowi to zwiększenie szerokości o 50% w stosunku do powszechnie stosowanych pasów 6 mm. Zwiększenie szerokości pasa redukuje rozciągliwość materiału pod wpływem naprężenia wstępnego oraz sił wynikających z dynamicznych przyspieszeń podczas pracy drukarki.

Dobór materiału wzmacniającego

Wybór materiału wzmacniającego rdzeń pasa napędowego GT2 jest krytycznym czynnikiem wpływającym na sprawność mechaniczną systemu CoreXY. Konieczne było zbalansowanie dwóch przeciwstawnych wymagań: minimalnej rozciągliwości (dla zachowania precyzji pozycjonowania) oraz elastyczności niezbędnej do pracy w złożonej geometrii pasa.

- Pasy wzmacniane stalą- pasy ze stalowym rdzeniem charakteryzują się minimalną rozciągliwością, co jest korzystne dla precyzji. Jednak, cechują się one niższą elastycznością. W skomplikowanej architekturze CoreXY, która wymaga wielokrotnego zginania pasa, pasy stalowe generowałyby nadmierne obciążenie na łożyska i silniki, prowadząc do zwiększonego momentu oporu i redukcji dynamiki układu.
- Pasy wzmacniane włóknem szklanym- pasy te wykazują nieco większą rozciągliwość niż pasy stalowe, w zamian oferują one znacznie wyższą elastyczność i odporność na zginanie.

Z uwagi na konieczność minimalizacji obciążeń przenoszonych na silniki, a także zapewnienia płynnej pracy w układzie z wieloma zmianami kierunku pasa, w projekcie zastosowano pasy napędowe GT2 wzmacniane włóknem szklanym.

Geometria prowadzenia pasów

Kolejnym aspektem konstrukcyjnym jest sposób prowadzenia pasów. W praktyce stosuje się dwa główne warianty:

Układ z pasami skrzyżowanymi
W metodzie tej oba paski przecinają się wizualnie, tworząc kształt „X".

Zalety:
- Silniki znajdują się na tej samej wysokości co znacznie ułatwia projektowanie.

Wady:
- Przecinające się pasy mogą zużywać się nierównomiernie, krzyżowanie wprowadza dodatkowe siły boczne, co może przyczyniać się do szybszego zużycia pasa i rolek.
- Trudniejsza regulacja – krzyżowanie wymaga precyzyjnego ustawienia i stabilnej ramy, każda odchyłka (błąd montażu, skrzywienie ramy) może prowadzić do niestabilności.

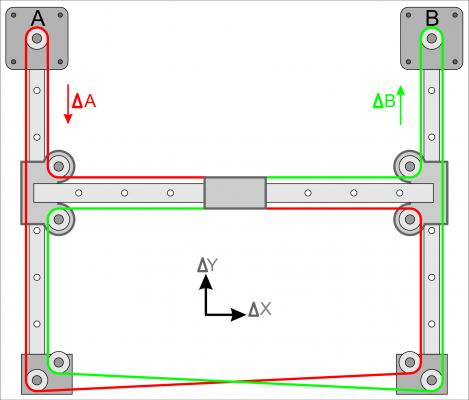
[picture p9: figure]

Rys. 32 Schemat układu CoreXY z pasami skrzyżowanymi. Źródło: [40].

Układ z pasami nieskrzyżowanymi:
W tej metodzie silniki krokowe są ustawione w taki sposób, że prowadnice pasków dla każdej pętli są umieszczone na różnych wysokościach, dzięki temu rozwiązaniu nie ma potrzeby krzyżowania pasków.

Zalety:
- Pasy biegną równolegle do prowadnic liniowych- zmniejsza to ryzyko nierównomiernego naprężenia i błędów geometrycznych.

- Łatwiejsza regulacja i utrzymanie prawidłowego naciągu.
- Wolniejsze zużycie pasa- brak krzyżowania eliminuje momenty skrętne, które prowadzić do ścierania krawędzi.

Wady:
- Silniki muszą być umieszczone na różnych wysokościach, co wymaga przemyślanego projektu ramy i konstrukcji mocowań.

Rys. 33. Schemat układu CoreXY z pasami nieskrzyżowanymi (równoległymi).

Mając na uwadze założenia projektu- jako optymalny sposób prowadzenia pasków przyjęto układ nieskrzyżowany. Oto powody uzasadniające tę decyzję:

- Stabilność napięcia i przewidywalność ruchu- równoległa geometria pasa zapewnia stałe naprężenie przy każdej pozycji głowicy.
- Mniejsze zużycie mechaniczne
- Łatwiejsza regulacja i serwis

Analiza naciągu paska

Napięcie pasa zębatego ma bezpośredni wpływ na dokładność pozycjonowania, powtarzalność i odporność na gubienie kroków. Istotnym, mierzalnym kryterium jest częstotliwość drgań najdłuższego odcinka paska po jego szarpnięciu. Przy odpowiednio dobranym napięciu częstotliwość ta mieści się w określonym bezpiecznym zakresie, dając przewidywalną sztywność układu.

Pasek napięty można w przybliżeniu traktować jak napiętą strunę [13]. Dla takiej struny częstotliwość fundamentalna φ opisuje wzór [13]:

φ =

1
2L

√
T
μ

gdzie:
φ – częstotliwość drgań [Hz]
L – długość drgającego odcinka paska [m] (w praktyce najdłuższy prosty segment paska)
T – siła napięcia paska [N]
µ - masa liniowa paska [kg/m]

Do obliczeń przyjęto parametry odpowiadające powszechnie stosowanym paskom GT2 9 mm wzmocnionym włóknem szklanym [14]:

µ ≈ 0,015kg/m
L =0,46m
T= 25N, 40N – typowe siły napięcia stosowana w innych projektach CoreXY

### 1. T = 25N

φ =

1

2 ∗ 0,46 √
25
0,015 ≈ 1,087 ∗ 40,82 ≈ 44,37Hz

### 2. T = 40N

φ =

1

2 ∗ 0,46 √
40
0,015 ≈ 1,087 ∗ 51,64 ≈ 56,13Hz

la zastosowanego paska optymalnym i bezpiecznym zakresem do ustawienia napięcia jest 45-55 Hz.

- Chcąc uzyskać wyższe prędkości druku należy napiąć pasek tak, aby drgał z częstotliwością 55 Hz
- Jeśli użytkownikowi zależy na wolniejszym zużyciu układu napędowego, optymalnym wyborem będzie 45-50 Hz

Przy naciąganiu paska należy pamiętać o identycznym napięciu obydwu pętli pasa. Naciąg paska realizowany jest poprzez regulację silnika M1 oraz M2 dla pętli 1 i 2 pasa napędowego.

Rys. 34. Wizualizacja mechanizmu naciągu paska poprzez przesuw silnika w gnieździe mocującym

### 3.5 System przełożenia napędu osi X/Y

System przełożenia napędu jest odpowiedzialny za konwersję ruchu obrotowego silników krokowych na ruch liniowy osi bramowej w płaszczyźnie poziomej. W projekcie zastosowano układ AWD (All Wheel Drive), co oznacza, że każda pętla paska napędzana jest przez dwa silniki.

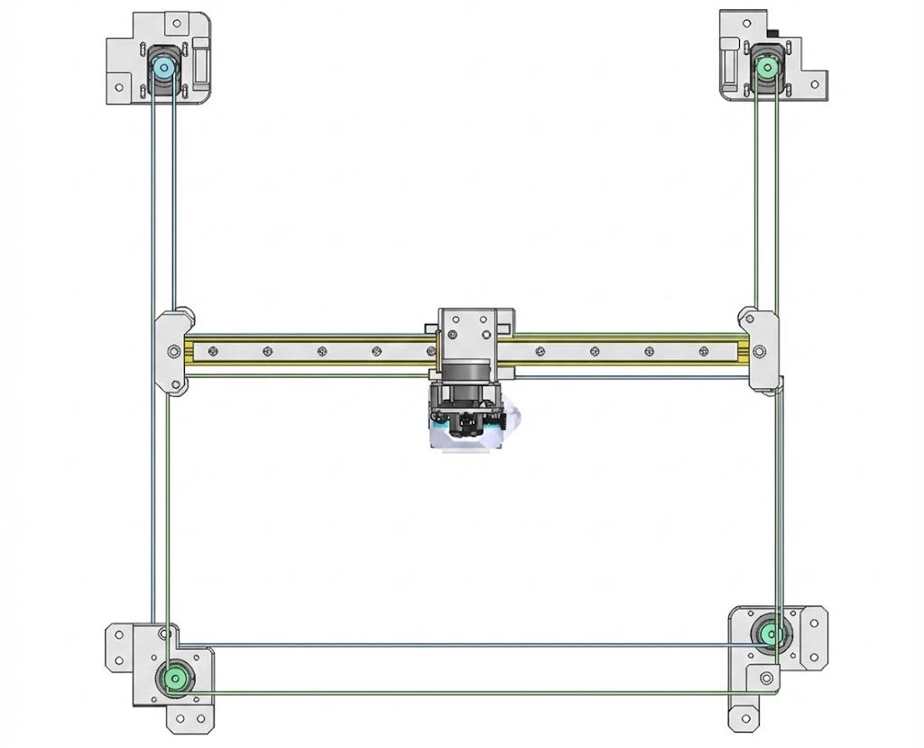
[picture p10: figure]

Rys. 35. Schematyczny rzut z góry na system napędu osi X/Y w układzie AWD.

Ruch osi generowany jest przez 4 silniki krokowe NEMA17 o kącie kroku 1,8° i momencie trzymającym 0,59 Nm. Aby uzyskać większe prędkości druku, w standardowe miejsca rolek prowadzących wstawiono dodatkowo dwa silniki, które poprzez szeregowe połączenie wspomagają pracę głównych silników napędowych.

Do konwersji ruchu obrotowego silników na ruch głowicy wykorzystano koła zębate GT2 o 20 zębach i rozstawie zębów 2 mm.

Liniowe przemieszczenie pasa na jeden pełen obrót wału silnika wynosi:

Przełożenie liniowe = 20 zębów ∗ 2mm/ząb = 40mm/obrót

Rozdzielczość pozycjonowania:

Kroki/mm =

200kroków

(

40mm
obrót

)

5kroków/mm = 0,2mm/krok

W praktyce oznacza to, że wykonując 1 krok silnikiem krokowym głowica przesunie się 0,2mm, jest to minimalny możliwy ruch głowicy bez stosowania mikrokroków.

Prowadzenie pasa napędowego:
Prowadzenie pasów w przyjętej topologii wymaga użycia licznych kół bieżnych, koła te mają 2 główne funkcje:

- Utrzymanie naciągu- wpływają na równomierne rozłożenie naprężenia wstępnego pasa.
- Definicja geometrii – utrzymują pas w ściśle określonej ścieżce, zapobiegając jego ocieraniu się o inne elementy konstrukcji oraz zapewniając idealną
- równoległość między poszczególnymi sekcjami systemu przełożenia napędu

Krytycznym wymogiem dla precyzji drukarki jest to, aby wszystkie ścieżki pasów znajdowały się w idealnie równoległych płaszczyznach do płaszczyzny ruchu osi X/Y. Nawet minimalne odchylenie od równoległości może prowadzić do:

- Generowania błędów pozycjonowania
- Wzrostu tarcia i opóźnień

W związku z tym, projektując system napędu osi X/Y i rozmieszczając rolki, należy wziąć pod uwagę nie tylko pozycję rolek względem siebie, ale również grubość paska oraz fakt, że średnica koła zębatego wraz z paskiem będzie się różniła od średnicy koła bezzębnego z założonym paskiem. Różnica ta wynika z faktu zazębiania się paska napędowego na kołach zębatych.

W przypadku użycia pasa napędowego firmy Gates, wartości te wynoszą [14]:

- średnica koła zębatego wraz z owiniętym paskiem – 13,9mm
- średnica koła bezzębnego wraz z owiniętym paskiem – 14,9mm

Oznacza to, że koła bieżne, nie mogą być ustawione idealnie równolegle w jednej linii, skutkowałoby to brakiem równoległości pasa napędowego.

Rys. 36. Rozmieszczenie kół bieżnych

Aby zapewnić odpowiednie rozmieszczenie kół bieżnych oraz silników krokowych, jednocześnie zapewniając odpowiednie napięcie pasa napędowego oraz sztywność całej konstrukcji zaprojektowane zostały mocowania tych elementów:

Rys. 37. Rysunek poglądowy mocowania silnika – lewy tył.

Rys. 38.Model 3D mocowania silnika – lewy tył.

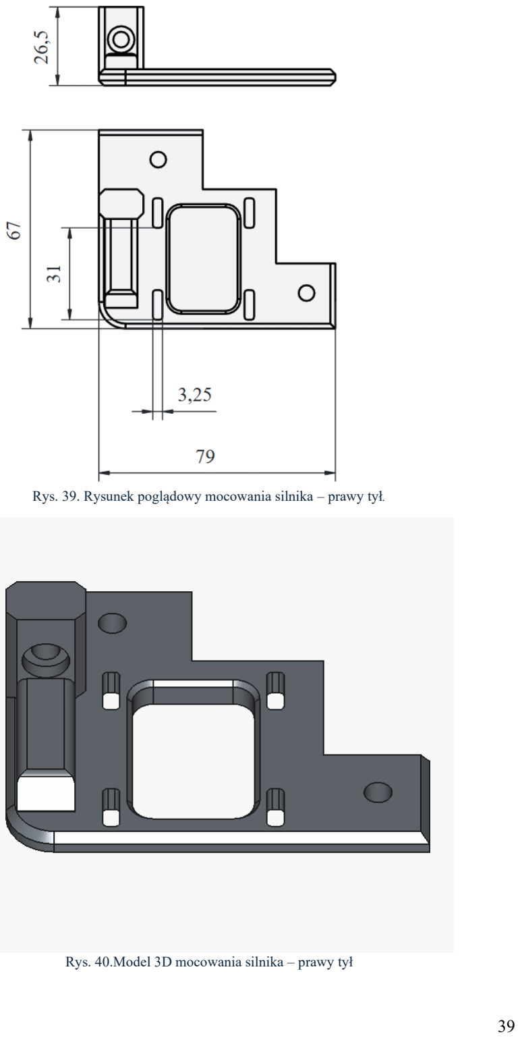
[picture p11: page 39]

Rys. 39. Rysunek poglądowy mocowania silnika – prawy tył.

Rys. 40.Model 3D mocowania silnika – prawy tył

Rys. 41. Rysunek poglądowy mocowania silnika i rolki prowadzącej lewy przód

Rys. 42 Model3D mocowania silnika i rolki lewy przód

Rys. 43. Rysunek poglądowy mocowania silnika i rolki prowadzącej prawy przód

Rys. 44. Model 3D mocowania silnika i rolki prowadzącej prawy przód

Technologia wywarzania:
Mocowania zaleca się wykonać z aluminium, jednak dopuszczalne jest również druk 3D z materiału ASA/ABS.
Dla maksymalizacji wytrzymałości zaleca się druk z następującymi parametrami:
- Dysza - 0,4mm
- Wysokość pierwszej warstwy – 0,15mm
- Wysokość warstwy – 0,2mm
- Obrysy – 6
- Zwarte warstwy górne/dolne – 7
- Wypełnienie – minimum 60%
- Rodzaj wypełnienia - Gyroid

### 3.6 Głowica drukująca

Głowica drukująca jest jednym z kluczowych podzespołów determinujących jakość, szybkość oraz niezawodność procesu druku 3D. Im lżejsza głowica, tym większe prędkości można uzyskać.

W zaprojektowanej drukarce zastosowano głowicę Dragon Burner V8 [17], w konfiguracji wyposażonej w:

- Czujnik KlickyNG Probe [42]
- Akcelerometr ADXL345
- Ekstruder Sherpa Mini [41]
- Wysokowydajny hotend Phaetus Dragon HF [19]

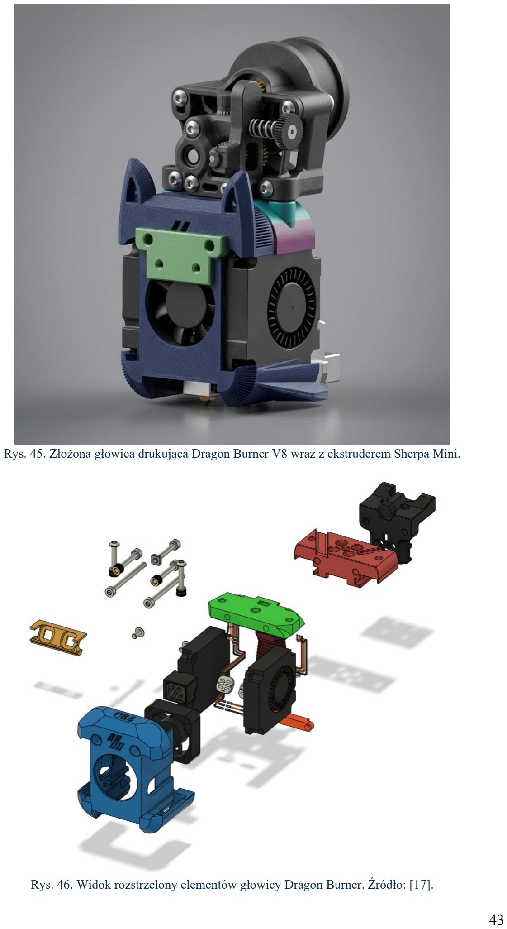
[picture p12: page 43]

Rys. 45. Złożona głowica drukująca Dragon Burner V8 wraz z ekstruderem Sherpa Mini.

Rys. 46. Widok rozstrzelony elementów głowicy Dragon Burner. Źródło: [17].

Dragon Burner V8 to lekki i modularny układ, zaprojektowany z myślą o drukarkach CoreXY pracującymi z wysokimi przyspieszeniami. Jego najważniejsze cechy to:

- Niska masa ruchoma (około 140-180g w zależności od konfiguracji)
- Wsparcie wielu hotendów zaprojektowanych z myślą o dużym przepływie, a co za tym idzie – dużej prędkości druku
- System chłodzenia druku zoptymalizowany pod wysokie przepływy materiału
- Kompatybilność z wieloma popularnymi czujnikami do automatycznej kalibracji
- Szerokie wsparcie społeczności

Dodatkowo zaprojektowano mocowania umożliwiające montaż głowicy na szynie MGN15, która jest częścią osi bramowej

Rys. 47. Rysunek poglądowy adaptera mocującego nr 1.

Rys. 48. Model 3D adaptera nr 1.

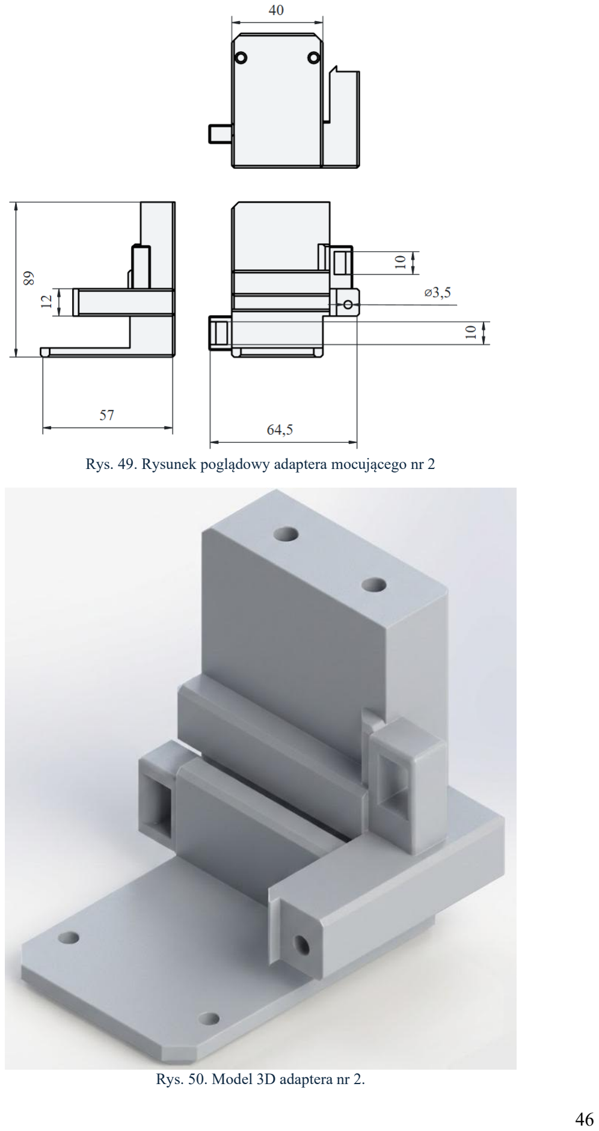
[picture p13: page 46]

Rys. 49. Rysunek poglądowy adaptera mocującego nr 2

Rys. 50. Model 3D adaptera nr 2.

Technika wykonania:
Mocowania zaleca się wykonać metodą druku 3D z materiału ASA/ABS.
Dla maksymalizacji wytrzymałości zaleca się druk z następującymi parametrami:
- Dysza - 0,4mm
- Wysokość pierwszej warstwy – 0,15mm
- Wysokość warstwy – 0,2mm
- Obrysy – 6
- Zwarte warstwy górne/dolne – 7
- Wypełnienie – minimum 70%
- Rodzaj wypełnienia – Gyroid

Mocowania zostały zaprojektowane w taki sposób, aby mocowanie nr1 przykręcane było do głowicy, następnie całość montowana jest na prowadnicy MGN15 i na końcu skręcana z mocowaniem nr 2. Połączenia elementów są połączeniami śrubowymi, w projekcie wykorzystano śruby M3 oraz gwintowane wkładki mosiężne, które należy wtopić w odpowiednie otwory. Mocowanie nr 2 przewiduje możliwość zamocowania ciężarków ołowianych, jeśli konieczne będzie wyważenie głowicy tak, aby środek jej ciężkości znajdował się idealnie na środku belki osi X/Y.

Hotend- zasada działania oraz uzasadnienie wyboru
Hotend jest kluczowym elementem każdej drukarki 3D typu FFF. Jego zadaniem jest:
- Stopienie filamentu w sposób kontrolowany
- Uformowanie jednorodnej strugi materiału wytłaczanej przez dyszę
- Stabilne utrzymanie temperatury
- Minimalizowanie strat cieplnych i zjawiska tzw. heat creep – niekontrolowanego przenikania ciepła do części zimnej

Hotend składa się z dwóch głównych stref:

- Strefa zimna – filament pozostaje w stanie stałym, wymaga dobrej wentylacji i izolacji od ciepła z bloku grzejnego
- Strefa gorąca – filament topi się i wytłaczany jest przez dyszę

Wysokiej jakości hotend wpływa bezpośrednio na:

- Stabilność przepływu materiału- hotend o dużej wydajności topienia pozwala drukować: szybciej, grubszymi warstwami, materiałami technicznymi
- Dokładność wymiarową- niestabilna temperatura powoduje zmiany objętości stopionego materiału, skutkuje to widocznymi różnicami między warstwami
- Brak problemów termicznych tj. niestabilna ekstruzja, zatykanie strefy zimnej materiałem – tworzenie się złogów filamentu.

Rys. 51. Schemat budowy hotendu z podziałem na strefy termiczne. Źródło:[18].

Rys. 52. Hotend Phaetus Dragon HF. Źródło: [19]

Hotend Phaetus Dragon High Flow wybrany został ze względu na:

- Kompatybilność z głowicą Dragon Burner V8
- Pełną separację bloku grzejnego od radiatora
- Możliwość pracy z szeroką gamą materiałów
- Bardzo wysoki przepływ 30-35mm³
/s
- Konstrukcję wykonaną w pełni z metalu

Ekstruder Sherpa Mini
Ekstruder jest głównym elementem układu podawania materiału w drukarce 3D. Jego zadaniem jest precyzyjne dozowanie filamentu do hotendu, w którym materiał jest topiony i wypychany przez dyszę.

Rys. 53. Ekstruder Sherpa Mini z silnikiem NEMA 14. Źródło: [41]

Ekstruder składa się z silnika krokowego, przekładni oraz mechanizmu dociskającego filament. W ekstruderach typu dual-drive, takich jak zastosowany w projekcie Sherpa Mini, filament jest chwytany symetrycznie przez dwa zazębiające się koła zębate. Zapewnia to dużą siłę docisku, wysoką kontrolę prędkości podawania i minimalizuje ryzyko poślizgów.

Ekstruder Sherpa Mini jest ekstruderem typu direct-drive- oznacza to, że umieszczony jest on bezpośrednio na głowicy drukującej. Takie rozwiązanie ma swoje zalety i wady:

Zalety:

- Najwyższa precyzja podawania filament
- Możliwość druku elastycznych materiałów
- Bardzo stabilna retrakcja, niezbędna przy wysokich prędkościach druku

Wady:
- Wyższa waga ruchoma głowicy
- Większe ryzyko artefaktów
- Bardziej skomplikowana konstrukcja mechaniczna

Alternatywą jest wybór ekstrudera typu Bowden (ekstruder zamontowany na ramie drukarki)
Ekstruder przepycha filament przez długą rurkę PTFE do głowicy

Zalety:
- Dużo niższa masa ruchoma na osi X/Y, skutkująca możliwością stosowania dużo większych przyspieszeń
- Prostsza konstrukcja głowicy

Wady:
- Opóźnienie reakcji na komendy ekstrudera (ze względu na sprężystość filament)
- Trudność w druku elastycznych materiałów (długa rurka sprawia, że materiały elastyczne bardzo często się w niej blokują)
- Gorsza kontrola przepływu przy wysokich prędkościach

Ekstruder Sherpa Mini został wybrany ze względy na swoją wysoką sprawność, niską masę oraz kompatybilność z głowicą Dragon Burner V8

Integracja systemu KlickyNG Probe:
Głowica Dragon Burner V8 przewiduje mocowanie dla zdejmowalnej sondy Klicky Probe. Stanowi ona część systemu automatycznego poziomowania wykorzystywanego w projekcie. Sonda ta została umieszczona na oddzielnym uchwycie kompatybilnym z głowicą drukującą, co umożliwia automatyczne podczepianie sondy przed pomiarem oraz jej odkładanie po zakończeniu procedury.
Klicky Probe mocowana jest magnetycznie za pomocą magnesów neodymowych, a jej baza jest drukowana z tworzywa ASA.

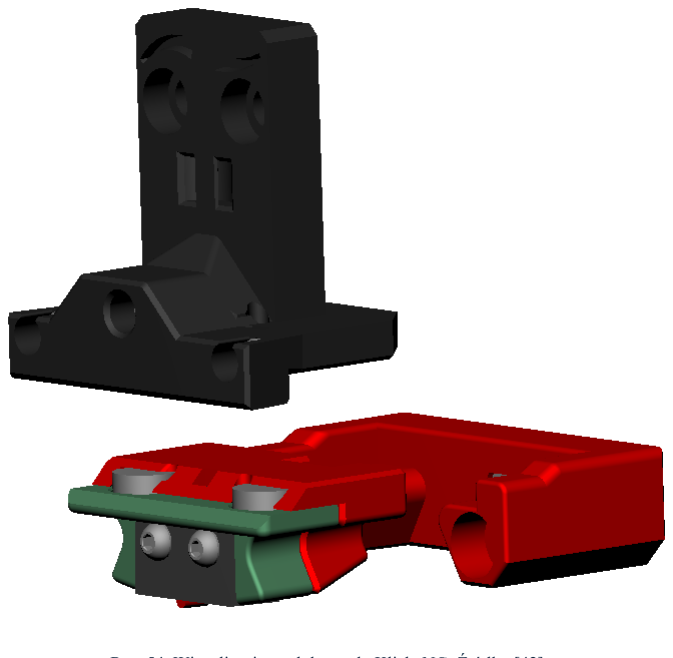
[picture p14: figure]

Rys. 54. Wizualizacja modułu sondy KlickyNG. Źródło: [42].

W celu integracji czujnika KlickyNG z projektem drukarki 3D, wykonane zostało mocowanie stacji dokującej, pozwala ono na montaż stacji dokującej czujnika do ramy drukarki.

Rys. 55. Wizualizacja miejsca montażu stacji dokującej czujnika KlickyNG do ramy

Rys. 56. Rysunek poglądowy mocowania stacji dokującej.

Rys. 57. Model 3D mocowania stacji dokującej.

Ze względu na to, że Klicky Probe jest układem zdejmowalnym, nie powoduje dodatkowych drgań na osi bramowej podczas ruchu głowicy. Jest to kluczowa zaleta w przeciwieństwie do stałych czujników montowanych na stałe razem z głowicą. Integracja ta stanowi idealne uzupełnienie lekkiej, wysokowydajnej głowicy Dragon Burner V8 wraz z lekkim ekstruderem Sherpa Mini oraz hotendem Phaetus Dragon HF.

### 3.7 Napęd osi Z

Oś Z w drukarce 3D odpowiada za precyzyjne pozycjonowanie zespołu roboczego w kierunku pionowym, inaczej mówiąc zmianę wysokości pomiędzy kolejnymi warstwami modelu. W zależności od przyjętej konstrukcji może to być realizowane poprzez ruch stołu roboczego lub głowicy drukującej. Niezależnie od rozwiązania konstrukcyjnego, poprawne działanie osi Z ma kluczowe znaczenie dla jakości i powtarzalności procesu druku.
Jednym z podstawowych zadań osi Z jest zapewnienie dokładnej wysokości warstwy. Błędy pozycjonowania w tym kierunku bezpośrednio przekładają się na nierówną grubość warstw. Może to prowadzić do pogorszenia jakości powierzchni, spadku wytrzymałości mechanicznej wydruku oraz widocznych defektów strukturalnych.

Szczególnie istotna jest pierwsza warstwa, której prawidłowe ułożenie warunkuje odpowiednią adhezję modelu do stołu roboczego. Zbyt mała lub zbyt duża odległość dyszy od powierzchni roboczej skutkuje odklejaniem się wydruku lub nadmiernym rozpływem materiału.
Oś Z ma również bezpośredni wpływ na stabilność całego procesu drukowania. Układ ten musi przenosić znaczne obciążenia wynikające z masy stołu roboczego, elementów grzejnych oraz drukowanego modelu, zachowując jednocześnie wysoką sztywność i odporność na drgania. W przeciwieństwie do osi X i Y odpowiedzialnych za szybkie ruchy głowicy w płaszczyźnie roboczej, oś Z pracuje z relatywnie niskimi prędkościami i przyspieszeniami. Jej głównym wymaganiem nie jest dynamika, lecz precyzja i powtarzalność pozycjonowania.

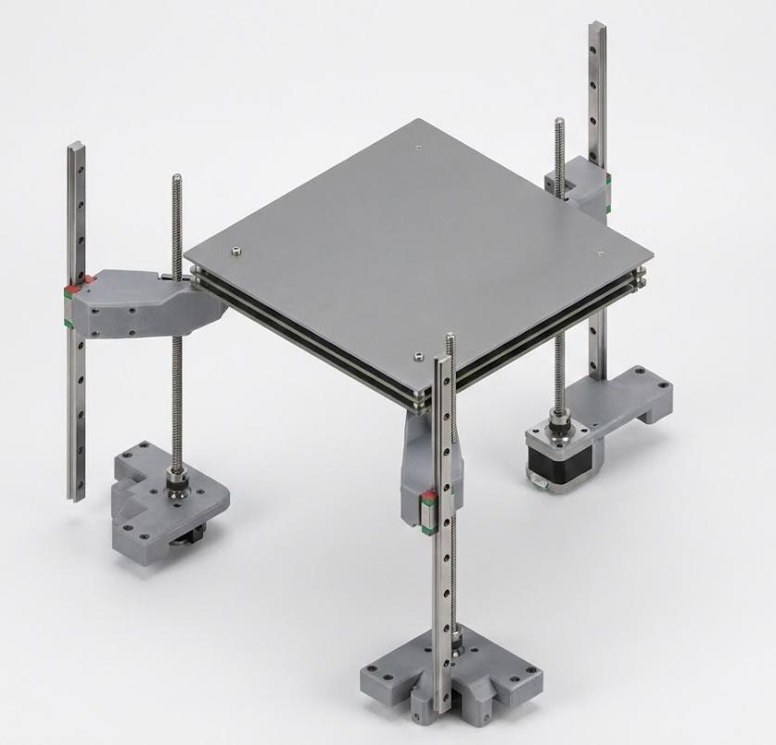
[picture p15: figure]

Rys. 58. Projekt kompletnego zespołu osi Z wraz ze stołem roboczym i mocowaniami.

Architektura mechanizmu osi Z
Architektura mechanizmu osi Z obejmuje zespół elementów odpowiedzialnych za przenoszenie ruchu napędowego, prowadzenie stołu roboczego oraz zapewnienie jego stabilnego i precyzyjnego pozycjonowania w kierunku pionowym.
W projektowanej drukarce 3D przyjęto rozwiązanie integrujące napęd śrubowy, liniowe prowadzenie ruchu oraz wielopunktowe podparcie stołu uzupełnione o możliwość automatycznej synchronizacji położenia za pomocą sterowania programowego.

Podstawę konstrukcji stanowi trójpunktowy układ podparcia stołu roboczego, realizowany za pomocą trzech niezależnych zespołów napędowych.

Rys. 59. Zespół napędowy osi Z

Legenda:

1- Silnik Nema17
2- Sprzęgło elastyczne aluminiowe 3- Śruba trapezowa T8x8 350mm
4- Mocowanie silnika do ramy
5- Nakrętka kasująca luz
6- Mocowanie stołu roboczego z napędem osi oraz prowadnicą liniową 7- Zespół stołu roboczego
8- Prowadnica liniowa MGN15
9- Rama drukarki

Każdy punkt podparcia składa się z wyżej wymienionych elementów. Zastosowanie trzech punktów podparcia pozwala na jednoznaczne określenie płaszczyzny roboczej stołu. Eliminuje to problem nadokreślenia geometrycznego, charakterystyczny dla układów czteropunktowych.

Śruby trapezowe pełnią funkcję elementów napędowych osi, przekształcając ruch obrotowy silników krokowych w ruch liniowy stołu. W celu zwiększenia dokładności pozycjonowania oraz ograniczenia luzu osiowego zastosowano nakrętki kasujące luz. Ich konstrukcja kompensuje luzy powstałe na styku gwintu śruby i nakrętki, co ma istotne znaczenie przy zmianach kierunku oraz podczas precyzyjnego ustawiania wysokości pierwszej warstwy.

Połączenie silników krokowych ze śrubami trapezowymi zrealizowano za pomocą sprzęgieł elastycznych. Sprzęgła umożliwiają kompensację niewielkich niewspółosiowości pomiędzy wałem silnika a śrubą i nakrętką. Redukuje to przenoszenie drgań oraz naprężeń na pozostałe elementy mechanizmu. Takie rozwiązanie zwiększa trwałość układu i poprawia kulturę pracy osi Z.

Prowadzenie ruchu stołu w osi Z zapewniają prowadnice liniowe MGN15. Ich zadaniem jest przejmowanie obciążeń bocznych oraz zapewnienie wysokiej sztywności i powtarzalności ruchu. Dzięki rozdzieleniu funkcji napędu (śruby trapezowe) i prowadzenia (prowadnice liniowe) uzyskano stabilny układ mechaniczny, odporny na skręcanie i ugięcia nawet przy dużej masie stołu roboczego i elementów grzejnych.

Połączenie tych elementów wymagało zaprojektowania mocowań zarówno stołu roboczego jak i silników realizujących napęd osi Z

Mocowania silników Nema17:

Rys. 60. Rysunek poglądowy tylnego mocowania silnika osi Z.

Rys. 61. Model 3D tylnego mocowania silnika.

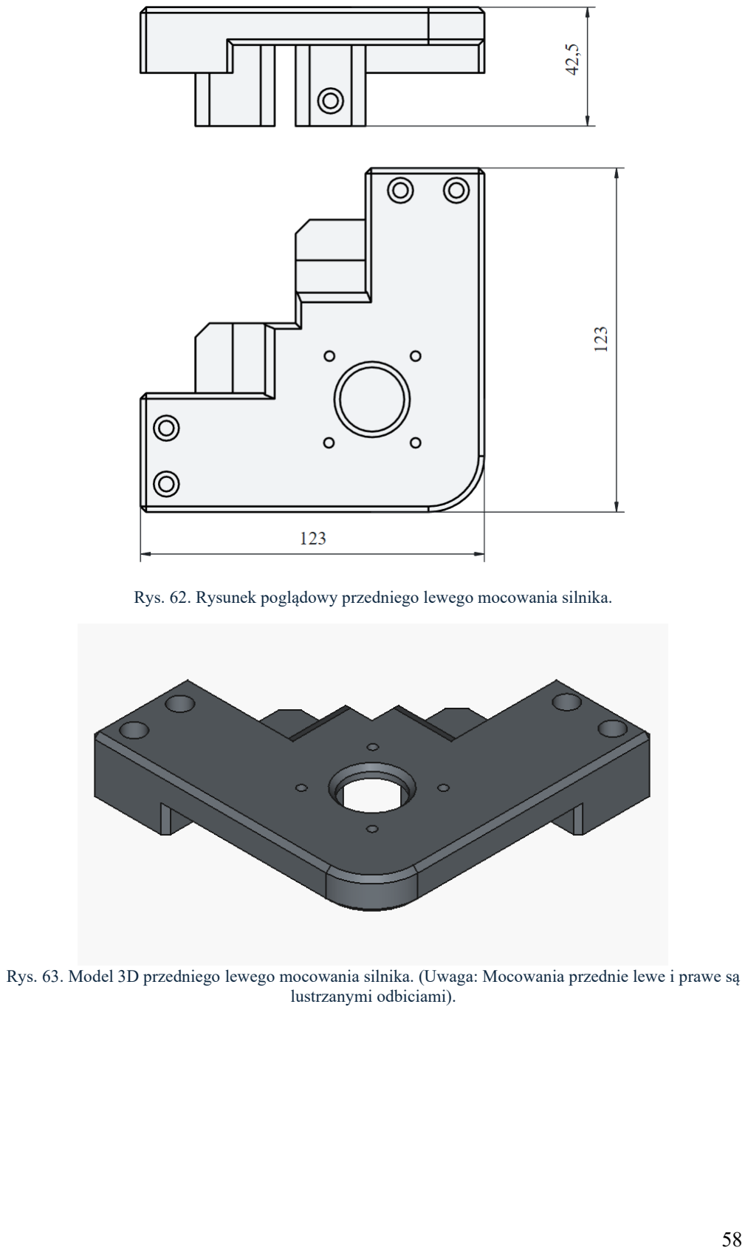
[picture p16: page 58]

Rys. 62. Rysunek poglądowy przedniego lewego mocowania silnika.

Rys. 63. Model 3D przedniego lewego mocowania silnika. (Uwaga: Mocowania przednie lewe i prawe są lustrzanymi odbiciami).

Rys. 64. Rysunek poglądowy tylnego ramienia stołu.

Rys. 65. Model 3D tylnego ramienia stołu.

Rys. 66. Rysunek poglądowy przedniego (lewego) ramienia stołu.

Rys. 67. Wizualizacja 3D przedniego lewego ramienia stołu. (Uwaga: Mocowania przednie lewe i prawe są lustrzanymi odbiciami)

Rozdzielczość mechaniczna osi Z:
Zastosowane silniki krokowe NEMA17 charakteryzują się kątem kroku równym 1,8°, co odpowiada 200 pełnym krokom na jeden obrót wału silnika. Przy bezpośrednim sprzężeniu silnika ze śrubą trapezową T8×8, której skok wynosi 8 mm na obrót, teoretyczna rozdzielczość mechaniczna osi Z wynosi:

∆Z =

8mm
200 = 0,04mm

Oznacza to, że jeden pełny krok silnika powoduje przemieszczenie stołu o 0,04mm. Taka rozdzielczość jest wystarczająca do realizacji typowych wysokości warstw stosowanych w druku 3D (np. 0,20mm, 0,24mm), które stanowią wielokrotność pełnego kroku silnika. Zapewnia to powtarzalność ruchu oraz stabilne pozycjonowanie bez konieczności polegania na mikrokrokach.

Wysokość pola roboczego osi Z:
Długość zastosowanych śrub trapezowych wynosi 350 mm, jednak rzeczywista wysokość pola roboczego osi Z jest mniejsza od długości całkowitej śruby. Wynika to z konieczności uwzględnienia elementów konstrukcyjnych:

a- Odległość do mocowania stołu roboczego -14mm
b- Grubość zespołu stołu roboczego – 36mm
c- Wysokość mocowania śruby w sprzęgle elastycznym – 12mm d- Zapas bezpieczeństwa -8mm
Zmax = 350mm − a − b − c − d = 280mm

W celu uzyskania większego pola roboczego osi Z dopuszczalne jest przesunięcie zespołu napędowego wraz z głowicą wyżej, a następnie wymiana śrub trapezowych na dłuższe. Szacunkowo pozwoliłoby to uzyskać pole robocze o wysokości około 330 mm bez zmieniania konstrukcji ramy. Wymagałoby to jednak przerobienia mocowań silników osi X/Y oraz wydłużenia profilu nr 5. Dalsze zwiększanie pola roboczego wymaga zmiany konstrukcji ramy drukarki na wyższą.

### 3.8 Zespół stołu roboczego

Zespół stołu roboczego jest jednym z głównych elementów konstrukcyjnych drukarki. Odpowiada on bezpośrednio za adhezję pierwszej warstwy wydruku oraz stabilność termiczną procesu wytwórczego. Projektowany moduł jest układem złożonym, składającym się z dwóch głównych podzespołów: ramy nośnej wykonanej z profili aluminiowych V-slot 2020 oraz płyty grzewczej.

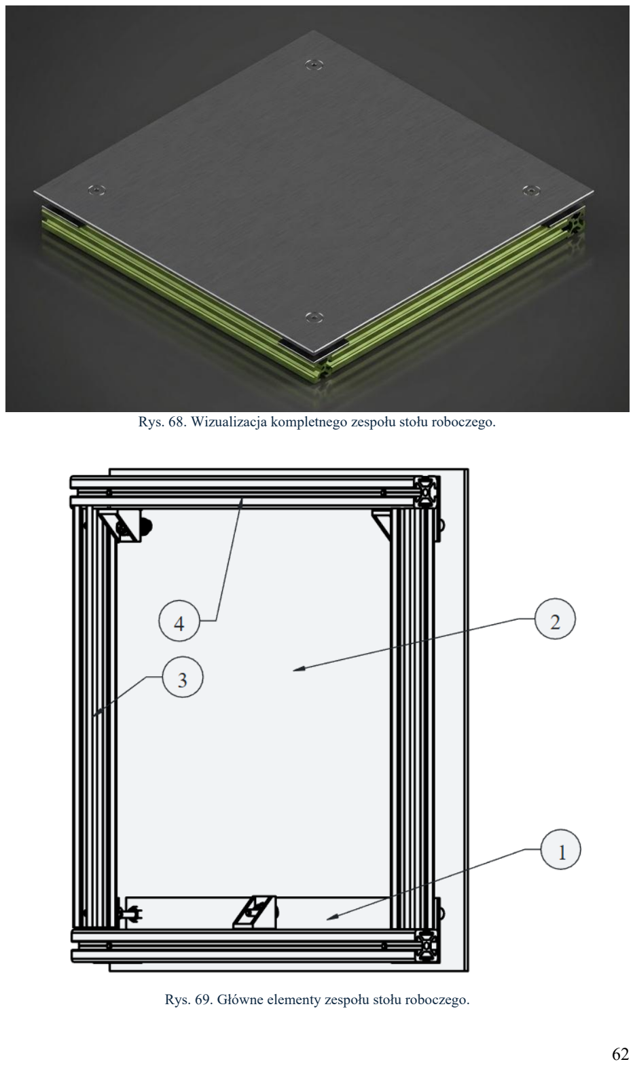
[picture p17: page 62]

Rys. 68. Wizualizacja kompletnego zespołu stołu roboczego.

Rys. 69. Główne elementy zespołu stołu roboczego.

Legenda:

1- Belka pośrednia – (płaskownik aluminiowy 20x260x5) 2- Grzana płyta aluminiowa
3- Profil 2020, element ramy stołu
4- Profil 2020 element ramy stołu

Realizacja założenia trójpunktowego podparcia bezpośrednio dla płyty grzewczej wymagała zastosowania dodatkowego rozwiązania konstrukcyjnego. Wynika to ze standardowej geometrii dostępnych stołów roboczych (posiadających cztery otwory montażowe w narożnikach). Bezpośrednie wykorzystanie wszystkich czterech punktów prowadziłoby do statycznej niewyznaczalności układu oraz ryzyka odkształcenia powierzchni pod wpływem naprężeń montażowych.
W celu adaptacji układu do systemu trójpunktowego w tylnej części zespołu zastosowano sztywną belkę pośrednią. Element ten łączy dwa tylne otwory montażowe stołu grzewczego w sposób sztywny, redukując je do jednego, centralnie
umieszczonego punktu podparcia. Punkt ten wyposażony w element sprężysty i śrubę regulacyjną współpracuje bezpośrednio z ramą nośną osi Z.

Rys. 70. Przekrój przez punkt regulacyjny poziomowania stołu.

Legenda:

1- Kątownik 2020
2- Śruba M3
3- Nakrętka M3
4- Sprężyna dociskowa
5- Grzana płyta aluminiowa

Ręczne poziomowanie stołu realizowane jest poprzez regulowane punkty mocowania płyty grzanej do ramy konstrukcyjnej. Płyta stołu została zamocowana do profili aluminiowych za pomocą śrub regulacyjnych współpracujących ze sprężynami dociskowymi. Umożliwiają one zmianę wysokości poszczególnych punktów stołu względem ramy drukarki.
Całość łączy kątownik aluminiowy 2020. Takie rozwiązanie pozwala na kompensację niewielkich odchyłek geometrycznych oraz wstępne ustawienie równoległości powierzchni roboczej względem płaszczyzny ruchu głowicy.

Rys. 71. Rysunek poglądowy ramy nośnej stołu.

Legenda:

1- Kątownik płaski
2- Śruba M5
3- Profil aluminiowy V-slot 2020 260mm
4- Profil aluminiowy V-slot 2020 300mm

Powierzchnia robocza stołu roboczego została zaprojektowana jako układ kompozytowy, składający się z trzech funkcjonalnych warstw:

1. Aluminiowy stół grzewczy – podstawa, odpowiadająca za dystrybucję ciepła
2. Samoprzylepna mata magnetyczna – interfejs mocujący
3. Zdejmowalna płyta robocza – właściwa powierzchnia adhezyjna dla drukowanego materiału

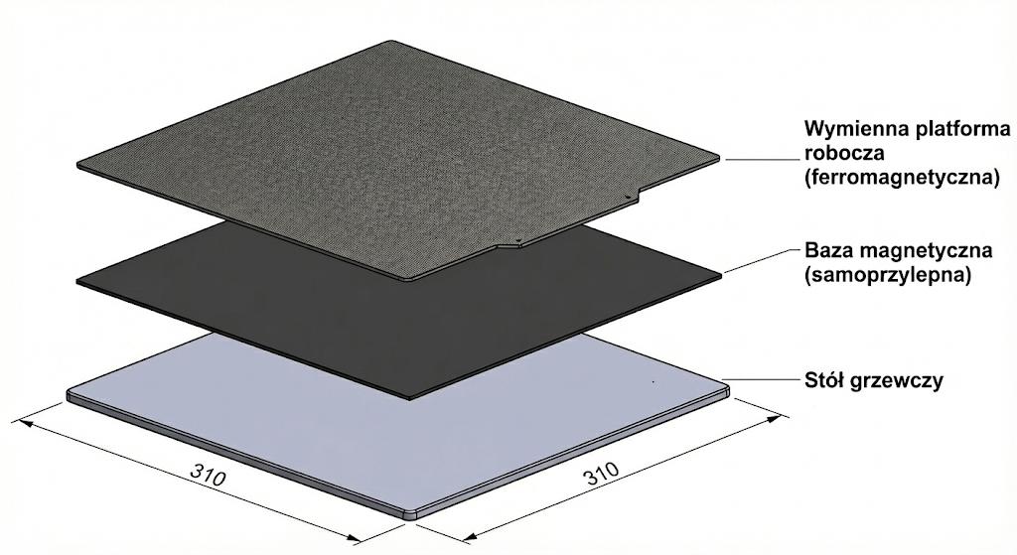
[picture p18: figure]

Rys. 72. Widok rozstrzelony warstw powierzchni roboczej stołu. Źródło: Opracowanie własne.

Taka konfiguracja pozwala na łatwy i szybki demontaż wydrukowanego modelu oraz zmianę platformy roboczej na inną.

### 4. Projekt elektryczny drukarki

### 4.1 Wprowadzenie do projektu elektrycznego

Projekt elektryczny drukarki 3D stanowi uzupełnienie zaprojektowanego układu mechanicznego i ma kluczowe znaczenie dla zapewnienia poprawnej pracy całego urządzenia. Jego głównym zadaniem jest realizacja sterowania ruchem osi, regulacja temperatury elementów grzejnych, obsługa czujników pomiarowych oraz zapewnienie bezpiecznego i stabilnego zasilania podzespołów drukarki.
Podczas gdy część mechaniczna odpowiada za zapewnienie sztywności, dokładności geometrycznej oraz odpowiedniej kinematyki układu ruchu, projekt elektryczny koncentruje się na przetwarzaniu sygnałów sterujących, dostarczaniu energii do elementów wykonawczych oraz akwizycji danych pomiarowych niezbędnych do prawidłowej pracy systemu.
Szczególne znaczenie ma tutaj synchronizacja pracy silników krokowych, precyzyjna kontrola temperatury hotendu i stołu roboczego oraz niezawodna detekcja położeń referencyjnych osi.
Projektowany system elektryczny został dostosowany do wymagań drukarki typu CoreXY z napędem wielosilnikowym. Zastosowane rozwiązania umożliwiają obsługę wysokich prędkości i przyspieszeń osi X/Y.

### 4.2 Architektura systemu sterowania

System sterowania zaprojektowanej drukarki 3D oparty jest na architekturze rozproszonej, charakterystycznej dla oprogramowania Klipper [26]. W przeciwieństwie do klasycznych rozwiązań (np. Marlin), gdzie jeden mikrokontroler odpowiada zarówno za obliczanie trajektorii ruchu, jak i generowanie sygnałów krokowych, tutaj zadania te zostały rozdzielone.
Jednostka nadrzędna (Host) o dużej mocy obliczeniowej przetwarza kod G-code i planuje ruch, natomiast jednostka wykonawcza (MCU) realizuje polecenia w czasie rzeczywistym.
Taka konfiguracja pozwala na osiągnięcie znacznie większych prędkości ruchu, implementację zaawansowanych algorytmów (np. kompensacja rezonansu), połączenie drukarki z Internetem czy wdrożenie systemu monitorującego wydruk w czasie rzeczywistym AI.

Rys.73 Schemat połączeń logicznych i komunikacyjnych systemu

Analiza struktury systemu:
Sercem układu wykonawczego jest płyta główna BigTreeTech Octopus Max EZ V1.0 (Primary MCU) [45]. Pełni ona rolę koncentratora sygnałów dla wszystkich peryferiów drukarki. Płyta komunikuje się z jednostką nadrzędną – komputerem jednopłytkowym Raspberry Pi 4B (Host Klipper) [46] – wykorzystując magistralę szeregową.

W architekturze systemu wyróżnia się trzy kluczowe sekcje:

1. Zasilanie– układ podzielony został na dwie niezależne sekcje w celu optymalizacji wydajności napędów.
- Sekcja 24V DC –zasila płytę główną, grzałki, wentylatory, silniki osi Z, silnik ekstrudera
- Sekcja 48V DC- Zasila napęd osi X/Y

Zastosowanie podwyższonego napięcia dla osi X/Y pozwala na uzyskanie lepszej charakterystyki momentu silników przy wysokich prędkościach oraz zmniejszenie prądów roboczych.

2. Ruch– Sterowanie silnikami krokowymi poprzez sterowniki dobrane pod kątem specyfiki danej osi:
- Oś Z – wykorzystuje trzy sterowniki TMC2209 pracujące w trybie UART.
- Oś XY- obsługiwana przez cztery sterowniki TMC5160, zasilane napięciem 48V, komunikujące się z płytą główną poprzez magistralę SPI.

Zastosowanie magistrali SPI w osi X/Y zapewnia wysoką przepustowość transmisji danych oraz możliwość zmiany parametrów prądowych w trakcie pracy.

3. Zasoby i peryferia– System integruje szereg czujników niezbędnych
- Termistory- monitorują temperaturę bloku grzejnego i stołu
- Sonda Klicky i czujnik filament – podpięte przez porty GPIO celem wykrywania stanu stołu roboczego oraz obecności materiału
- Akcelerometr – podłączony jako drugorzędne MCU, służy do kalibracji rezonansów mechanicznych.

Pomiary temperatury realizowane są z wykorzystaniem termistorów podłączonych do wejść analogowych płyty głównej, wyposażonych w przetworniki analogowo-cyfrowe (ADC. Sygnały te przetwarzane są przez firmware w celu bieżącej kontroli stanu termicznego układu)
Protokoły komunikacyjne w systemie:
- USB (Universal Serial Bus) – jest głównym kanałem komunikacyjnym pomiędzy Raspberry Pi 4B, a płytą główną Octopus. Przesyłane są tędy instrukcje ruchu oraz dane zwrotne z czujników. USB wykorzystano również do komunikacji z akcelerometrem
- UART (Universal Asynchronous Reciever-Transmitter) – Wykorzystany do dwukierunkowej komunikacji ze sterownikami TMC2209.
- SPI (Serial Peripheral Interface) Zastosowany dla sterowników TMC5160. Jest to magistrala synchroniczna o wysokiej przepustowości, kluczowa do dynamicznej zmiany parametrów prądowych w trakcie druku

Sterowanie elementami wykonawczymi o dużej mocy, takimi jak grzałka hotendu i stół grzewczy, realizowane jest za pomocą tranzystorów MOSFET wbudowanych w płytę główną. Umożliwiają one modulację mocy dostarczonej do odbiorników metodą PWM, co pozwala na precyzyjną regulację temperatury.

### 4.3 Sterowniki i silniki krokowe

Zasada działania silnika krokowego[20]:
Silnik krokowy to maszyna elektryczna, w której impulsy elektryczne zamieniane są na ruch obrotowy wirnika [21]. W przeciwieństwie do klasycznych silników DC, kąt obrotu jest bezpośrednio proporcjonalny do liczby podanych impulsów, a prędkość obrotowa do ich częstotliwości.

Rys.74 Budowa hybrydowego silnika krokowego Źródło: [43]

Rys. 75. Schemat ideowy dwufazowego silnika krokowego. Źródło: [21].

Sterowanie silnikiem krokowym [22]
Aby silnik krokowy mógł wykonać ruch, sterownik musi zmieniać kierunek przepływu prądu w cekach stojana. Służy do tego układ zwany mostkiem. Każda faza silnika posiada własny, niezależny mostek H.
Budowa i zasada działania mostka H
Mostek H składa się z czterech przełączników (w użytym sterowniku TMC 5160, są to tranzystory MOSFET) skonfigurowanych w kształt litery „H”
- Kierunek 1 – zamknięcie przekątnych przełączników powoduje przepływ przez cewkę w jedną stronę.
- Kierunek 2 – zamknięcie drugiej pary przełączników, zmienia polaryzację cewki, odwracając kierunek pola magnetycznego
- Hamowanie: zamknięcie obu dolnych przełączników zwiera cewkę, co indukuje siłę przeciw-elektromotoryczną hamującą wirnik

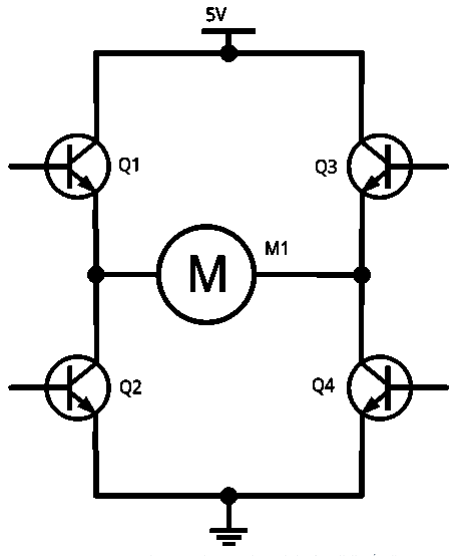
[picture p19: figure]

Rys. 76. Uproszczony schemat mostka H sterującego jedną fazą silnika. Źródło:[22].

Mikrokroki
W procesie mikrokrokowania sterownik wykorzystuje technikę PWM do precyzyjnego kontrolowania natężenia prądu w każdej fazie [44]. Pozwala to na „zatrzymanie" pola magnetycznego w dowolnej pozycji pośredniej pomiędzy pełnymi krokami.

Zalety mikrokroku w systemie CoreXY:

- Zwiększenie rozdzielczości pozycjonowania
- Redukcja rezonansów – płynniejsze przejścia prądowe minimalizują drgania mechaniczne ramy
- Cichsza praca

Rys. 77. Porównanie przebiegów prądowych: pełny krok, półkrok i mikrokrok. Źródło: [44].

Wybór sterowników i silników krokowych
W projekcie wykorzystano sterowniki BigTreeTech TMC2209EZ oraz TMC5160EZ, bazujące na technologii firmy Trinamic. Wprowadzają one funkcję interpolacji kroków – jednostka MCU wysyła sygnały z rozdzielczością 1/16 kroku, a sterownik wewnętrznie dzieli każdy mikrokrok na 256 mniejszych części.
Jest to kluczowe w układzie AWD, gdzie synchronizacja czterech silników przy wysokich prędkościach generuje ogromną liczbę instrukcji ruchu.

Wybór silników krokowych
Dobór jednostek napędowych był bezpośrednio podyktowany wymaganiami kinematyki CoreXY oraz założeniem osiągania wysokich prędkości druku przy zachowaniu dużej precyzji pozycjonowania. W projekcie zastosowano silniki NEMA 17 o podwyższonym momencie trzymającym 0,59Nm co w połączeniu z architekturą AWD stanowi o wydajności układu ruchu.

Rys. 78. Specyfikacja techniczna zastosowanych silników krokowych. Źródło: Dokumentacja producenta.

W tradycyjnych konstrukcjach CoreXY za ruch w płaszczyźnie X/Y odpowiadają dwa silniki. W tym projekcie zdecydowano się na zastosowania czterech silników dla osi X/Y. Decyzja ta wynika z następujących zalet:

- Redukcja błędów pozycjonowania – rozkład sił napędowych na cztery punkty pozwala na lepszą kontrolę napięcia długich pasów napędowych
- Zwiększenie dynamiki – sumaryczny moment obrotowy dostępny dla układu pozwala na stosowanie ekstremalnie wysokich przyspieszeń bez ryzyka gubienia kroków
- Stabilność termiczna – przy czterech silnikach obciążenie przypadające na jedną jednostkę jest relatywnie niższe podczas standardowej pracy, przekłada się to na niższą emisje ciepła i dłuższą żywotność komponentów

Teoretyczne osiągi napędu [23]
W celu zweryfikowania poprawności doboru silników oraz oszacowania maksymalnych parametrów dynamicznych drukarki, przeprowadzono analizę sił w układzie CoreXY AWD.
Wyprowadzenie wzoru bazowego:
Moment obrotowy(M) potrzebny do wygenerowania siły ciągu (F) na kole pasowym o promieniu (r) wyraża się wzorem:
M =

F ∗ r
η
gdzie:
M – moment obrotowy silnika [Nm]

F- siła liniowa przekazywana na pasek [N] r- promień koła pasowego [m]
η- sprawność mechaniczna układu

Aby obliczyć przyspieszenie (a), należy przekształcić ten wzór tak, aby wyznaczyć siłę (F), a następnie skorzystać z II zasady dynamiki Newtona (F = m * a).

F =

M ∗ η
r

Ponieważ w systemie AWD pasek napędzany jest przez więcej niż jeden silnik, siły sumują się:

Fcałkowita = F ∗ N =

N ∗ M ∗ η
r
gdzie:
N – liczba pracujących silników

Podstawiając siłę całkowitą do wzoru na przyspieszenie (a= F/m) uzyskujemy:

a =

N ∗ M ∗ η
m ∗ r
Do obliczeń przyjęto parametry wynikające z projektu mechanicznego oraz specyfikacji technicznej komponentów.
- Masa układu ruchomego – około 2kg (suma masy wózka osi X, głowicy drukującej oraz profilu poprzecznego)
- Promień koła pasowego – 6mm
- Moment trzymający silnika – 0,59Nm
- Liczba aktywnych silników (N) -2
- Sprawność η – 0,9

Producent podaje moment trzymający 0,59Nm, jest to wartość statyczna. W trakcie ruchu moment silnika krokowego spada, do obliczeń przyjęto bezpieczny moment roboczy na poziomie 50% momentu trzymającego, tak aby zagwarantować brak gubienia kroków przy wyższych prędkościach.

Mroboczy = 0,5 ∗ 0,59Nm = 0,295Nm

Mimo, że drukarka posiada 4 silniki, do obliczeń przyjęto N = 2. Wynika to z kinematyki układu CoreXY w której, najbardziej wymagającym ruchem jest ruch głowicy po przekątnej (45°). Aby głowica poruszała się idealnie po skosie, jeden pasek musi się poruszać, a drugi musi stać w miejscu. Oznacza to, że pasek A napędzany jest przez 2 silniki kręcące się w tym samym kierunku, natomiast pasek B jest trzymany w pozycji przez pozostałe 2 silniki. Podsumowując cała masa układu jest rozpędzana siłą pochodzącą od 2 silników.

Obliczenia końcowe:

amaks =

2 ∗ 0,295Nm ∗ 0,9
2kg ∗ 0,006m

= 44.25m/s

2

Maksymalne teoretyczne przyspieszenie układu, wynosi 44,25m/s² wartość ta znacznie przewyższa typowe wartości stosowane w druku 3D, oznacza to, że zastosowane silniki, zapewniają duży zapas mocy. W praktyce limitem prędkości i przyspieszenia będzie sztywność pasów zębatych oraz wytrzymałość ramy na wibracje.

### 4.4 Jednostka centralna i integracja sprzętowa

Jako główny kontroler drukarki dobrano płytę BigTreeTech Octopus Max EZ. Decyzja ta podyktowana była specyficznymi wymaganiami projektu, kluczowe kryteria doboru obejmują:

- Liczba kanałów sterowania: Zaprojektowany system napędowy oraz układ poziomowania stołu wymagają niezależnego wysterowania łącznie 8 silników krokowych (4x oś XY, 3x oś Z, 1 x ekstruder). Dobrana płyta oferuje 10 gniazd sterowników, co zapewnia pełną obsługę wszystkich osi oraz pozostawia rezerwę na ewentualną rozbudowę urządzenia
- Moc obliczeniowa: Sercem płyty jest 32-bitowy mikrokontroler ARM Cortex-M7 taktowany zegarem 550Mhz. Tak wysoka częstotliwość pracy jest niezbędna do generowania stabilnych sygnałów bez opóźnień, co jest krytyczne przy prędkościach druku przekraczających 300mm/s i wykorzystaniu interpolacji mikrokrokowej
- Obsługa wysokiego napięcia: Płyta jest sprzętowo przystosowana do pracy z napięciem silników do 60V. Dedykowane sekcje zasilania pozwalają na bezpieczne doprowadzenie napięcia 48V DC bezpośrednio do gniazd sterowników osi X/Y, eliminując konieczność stosowania zewnętrznych modułów separujących. Dodatkowo płyta ta umożliwia wybór sterowania wysokim i niskim napięciem każdego podpiętego silnika.

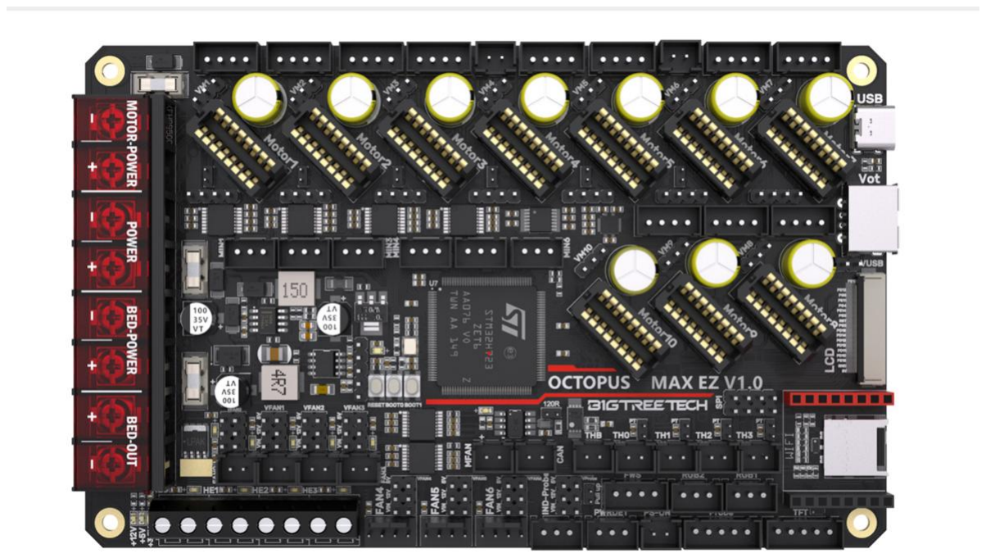
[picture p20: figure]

Rys. 79. Płyta główna BigTreeTech Octopus Max EZ V1.0 z widocznymi gniazdami sterowników. Źródło: [45]

Jednostka nadrzędna – Raspberry Pi 4B
Funkcję komputera nadrzędnego (Host) odpowiedzialnego za przetwarzanie kodu Gcode i zarządzanie logiką drukarki, pełni Raspberry Pi 4B. Wybór tej jednostki wynika z wymagań środowiska Klipper, które przenosi ciężar obliczeń matematycznych z mikrokontrolera na minikomputer o architekturze zbliżonej do komputerów personalnych (PC)
Główne zadania realizowane przez Raspberry Pi w projekcie to:
- Planowanie trajektorii ruchu: Przeliczanie w czasie rzeczywistym ścieżek narzędzia z uwzględnieniem limitów prędkości, przyspieszeń i szarpnięć
- Obsługa Input Shaper: Wykonywanie transformaty Fouriera (FFT) na danych z akcelerometru w celu identyfikacji częstotliwości rezonansowych ramy.
- Interfejs sieciowy: Hostowanie serwera WWW, umożliwiającego zdalne sterowanie drukarką, przesyłanie plików oraz podgląd z kamery

Rys. 80. Komputer jednopłytkowy Raspberry Pi 4 Model B. Źródło: [46].

Połączenie pomiędzy jednostką nadrzędną (Raspberry Pi) a wykonawczą (Octopus) realizowane jest za pośrednictwem interfejsu USB-C. Zapewnia on wysoką przepustowość transmisji danych, niezbędną do przesyłania tysięcy instrukcji ruchu na sekundę.

### 4.5 Układ zasilania

Niezawodność drukarki 3D oraz bezpieczeństwo jej użytkowania zależą bezpośrednio od stabilności i wydajności układu zasilania. Projekt zakłada zastosowanie napędów wysokonapięciowych (48V) dla osi X/Y oraz rozbudowanego systemu grzewczego – podgrzewany stół roboczy 310x310 oraz możliwość rozbudowy projektu o grzaną komorę. Wymaga to zastosowania dwóch zasilaczy impulsowych 24V- jako standard zasilania płyty głównej, wentylatorów, grzałek i 48V- zasilanie napędu osi X/Y.

Szacunkowy bilans mocy:
W celu doboru odpowiednich jednostek zasilających przeprowadzono analizę zapotrzebowania na moc elektryczną. Do obliczeń przyjęto założenie pracy w warunkach skrajnych, co oznacza jednoczesne nagrzewanie stołu, głowicy oraz ruch wszystkich osi z maksymalnym przyspieszeniem.

Tab.3 Bilans energetyczny podzespołów drukarki
Podzespół | Napięcie zasilania [V] | Szacowany prąd maksymalny [A] | Moc szczytowa [W] | Uwagi
Stół grzewczy | 24 DC | 12,5 | 300 | Główny odbiornik mocy
Grzałka głowicy | 24 DC | 2,5 | 60 | Grzałka ceramiczna o wysokiej wydajności
Silniki osi Z (3sztuki) | 24 DC | 3,0 | 72 | Praca przerywana
Silnik ekstrudera | 24 DC | 0,8 | 20 | Nema 14
Wentylatory i logika | 24 DC | 2,0 | 48 | Chłodzenie wydruku, hotendu
Raspberry pi4 B | 5 DC | 3,0 | 15 | Zasilanie przez przetwornicę step-down z linii 24V
Silniki osi X/Y (4sztuki) | 48 | 8,0 | 192 | Praca w układzie CoreXY
Suma -linia 24V | - | - | 515 | -
Suma – linia 48V | - | - | 192 | -

Na podstawie powyższych obliczeń dobrano jednostki zasilające z zachowaniem marginesu bezpieczeństwa (około 20%), co gwarantuje pracę zasilaczy w optymalnym zakresie sprawności i zapobiega ich przegrzewaniu.

1. Sekcja systemowa- zasilacz 24V DC-600W
2. Sekcja napędowa – zasilacz 48V DC-250W

Rys. 81. Schemat dystrybucji zasilania

Wraz ze wzrostem prędkości obrotowej wirnika, w uzwojeniach silnika indukuje się siła przeciw-elektromotoryczna, która skierowana jest przeciwnie do napięcia zasilającego. Przy standardowym zasilaniu 24V, siła ta bardzo szybko równoważy napięcie zasilania, uniemożliwiając przepływ prądu o zadanym natężeniu. Skutkuje to gwałtownym spadkiem momentu obrotowego przy wyższych prędkościach. Zastosowanie napięcia 48V przesuwa ten punkt krytyczny w zakres znacznie wyższych obrotów.

Wspólna masa układu (Common Ground)
Pomimo zastosowania dwóch niezależnych zasilaczy, projekt przewiduje galwaniczne połączenie biegunów ujemnych (GND) obu jednostek. Jest to warunek konieczny dla zapewnienia wspólnego potencjału odniesienia dla sygnałów sterujących przesyłanych między płytą główną a sterownikami silników HV

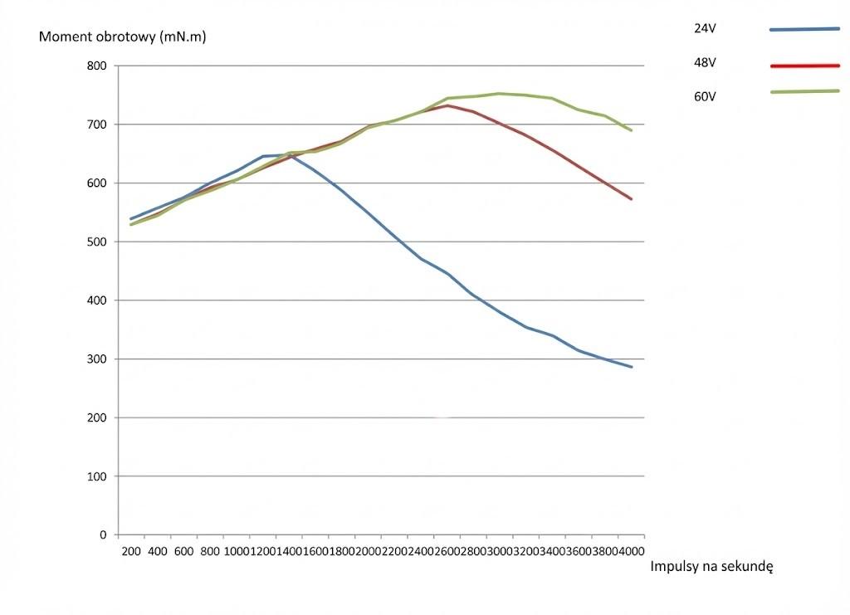
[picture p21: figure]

Rys. 82. Porównanie charakterystyki momentu obrotowego silnika krokowego w funkcji prędkości dla napięć 24V, 48V i 60V. Źródło: [21].

W projekcie wykorzystano zasilacze typu impulsowego (SMPS- Switching Mode Power Supply). W przeciwieństwie do tradycyjnych zasilaczy transformatorowych, oferują one sprawność powyżej 90% oraz niewielkie gabaryty, co ułatwia ich montaż w obudowie drukarki.

Zasada działania:
Działanie zasilacza impulsowego opiera się na przetwarzaniu energii z wykorzystaniem wysokich częstotliwości. Proces ten przebiega w kilku etapach:
1. Prostowanie-napięcie sieciowe 230V AC jest prostowane i filtrowane
2. Kluczowanie- tranzystor mocy (MOSFET) „szatkuje” napięcie stałe na impulsy o wysokiej częstotliwości

3. Transformacja i regulacja: impulsy trafiają na transformator impulsowy, gdzie napięcie jest obniżane. Układ sterujący poprzez zmianę szerokości impulsów (PWM) stabilizuje napięcie wyjściowe niezależnie od obciążenia, co jest kluczowe przy skokowym poborze prądu.

Rys. 83. Schemat blokowy zasilacza impulsowego. Źródło: [24].

Dobór okablowania
- Obwody wysokoprądowe – największym odbiornikiem energii jest stół grzewczy (12,5A). Zastosowanie zbyt cienkich przewodów skutkowałoby niebezpiecznym nagrzewaniem się izolacji. Projekt przewiduje zastosowanie przewodów 2,5mm² w izolacji silikonowej. Izolacja silikonowa odporna jest na wysokie temperatury i zachowuje elastyczność. Duży przekrój minimalizuje rezystancję przewodu, zapewniając dostarczenie pełnej mocy do grzałki
- Obwody napędowe (silniki 48V) – przy zasilaniu napięciem 48V i stromych zboczach sygnałów prądowych wymuszanych przez sterowniki, długie przewody fazowe działają jak anteny, emitujące zakłócenia elektromagnetyczne. Z tego powodu zastosowano przewody typu skrętka 0,8mm²
. Skręcenie par
przewodów fazowych (A+ z A- oraz B+ z B-) powoduje wzajemne zniesienie się pól magnetycznych generowanych przez przepływający prąd, co znacznie redukuje emisję zakłóceń do otoczenia
- Obwody silników 24V- Przy niskich prędkościach zasilanie 24V jest w pełni wystarczające, stosowanie napięcia 48V dla tych silników nie przyniosłoby żadnych korzyści, zastosowano przewody o przekroju 0,5mm²
, przewody te nie
wymagają dodatkowego ekranowania, jednak poprowadzone muszą być z dala od wiązki 48V
- Głowica drukująca – przewody doprowadzone do głowicy drukującej poddawane są ciągłemu zginaniu, zastosowano więc przewody typu FLRY o dużej liczbie cienkich żył miedzianych, zapewniają one wysoką elastyczność i odporność na tysiące cykli zginania.
- Sygnały i czujniki –0,14mm²
- Grzałka głowicy – 1mm²
- Zasilanie główne 2,5mm²

Bezpieczeństwo instalacji
Ze względu na obecność metalowych elementów ramy oraz napięcia sieciowego 230V wdrożono następujące środki ochrony:
- Uziemienie: Rama drukarki, obudowy zasilaczy oraz metalowa płyta stołu roboczego zostały połączone przewodem ochronnym z uziemieniem sieci
- Zabezpieczenia: Zastosowano bezpiecznik topikowy na wejściu zasilania
- Okablowanie: Przewody wysokoprądowe poprowadzono w izolacji odpornej na temperaturę, a połączenia śrubowe zabezpieczono tulejkami zaciskowymi.
- Przewód zasilający 230V należy wyposażyć w dławicę zapobiegającą jego wyrwaniu z obudowy
- Połączenia wysokoprądowe (stół grzewczy) zrealizowano przy użyciu złączy XT60, co eliminuje ryzyko iskrzenia

Szczegółowy schemat ideowy połączeń elektrycznych, uwzględniający piny mikrokontrolera, zamieszczono w załączniku nr 1.

### 4.6 Czujniki i układ regulacji procesowej

Kontrola temperatury jest procesem krytycznym dla przetwórstwa tworzyw termoplastycznych. Projektując drukarkę 3D konieczne było dobranie czujników, które zapewnią odpowiednią rozdzielczość pomiarową temperatur roboczych, oraz kompatybilność z elektroniką sterującą.

Analiza i dobór czujników temperatury
Na rynku dostępne są trzy główne technologie pomiaru temperatury w druku 3D
1. Termopary (Typ K)
2. Czujniki rezystancyjne RTD (PT100, PT1000)
3. Termistory (NTC 100k)

Standardowo w drukarkach 3D powszechnie stosuje się termistory NTC 100K. Jednak w niniejszym projekcie zastosowano czujniki rezystancyjne PT1000

Rys. 84. Czujnik PT100 w połączeniu 2 przewodowym. Źródło [53]

Uzasadnienie doboru
- Zakres pomiarowy: Termistory NTC tracą rozdzielczość pomiarową powyżej 260℃, a ich charakterystyka staje się silnie nieliniowa. Czujnik PT1000 zachowuje liniowość i wysoką dokładność w zakresie do 450 -500℃. Pozwala to na dokładniejsze kontrolowanie temperatury przy druku materiałami technicznymi (np. Nylon)
- Stabilność i dokładność: PT1000 to standard przemysłowy, w przeciwieństwie do tanich termistorów NTC, które często posiadają rozrzut produkcyjny rzędu 3-5%, markowe czujniki PT1000 oferują precyzję rzędu ± 0,3℃.

Pomiary i regulacja temperatury
PT1000 jest czujnikiem typu RTD (Resistance Temperature Detector) o dodatnim współczynniku temperaturowym (PTC). Oznacza to, że jego opór rośnie liniowo wraz ze wzrostem temperatury. Pomiar realizowany jest przez układ dzielnika napięcia na płycie głównej. Mikrokontroler odczytuje spadek napięcia przez przetwornik ADC i przelicza go na temperaturę.

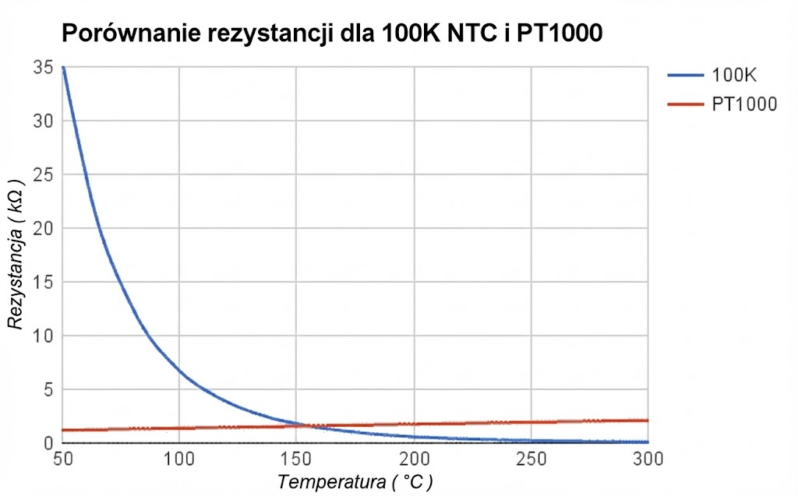
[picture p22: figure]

Rys. 85. Porównanie charakterystyki rezystancji w funkcji temperatury dla termistora NTC 100K i czujnika PT1000. Źródło: [25]

Sterowanie mocą grzałek – modulacja PWM:
Elementy grzejne sterowane są cyfrową metodą PWM (Pulse Width Modulation). Napięcie zasilania, nie jest obniżane, lecz kluczowane (włączane i wyłączne) z wysoką częstotliwością.
Współczynnik wypełnienia – określa stosunek czasu włączenia grzałki do czasu trwania całego impulsu.
Sterowanie PWM pozwala na płynną regulację średniej mocy dostarczanej do grzałki, mimo że element wykonawczy działa w trybie dwóch stanów (on, off)

Rys. 86. Wykres sygnałów PWM o różnym współczynniku wypełnienia. Źródło: [26].

Algorytm regulacji PID:
Aby wyeliminować oscylacje temperatury charakterystyczne dla sterowania sygnałem PWM, konieczna jest implementacja regulatora PID. Sterownik wylicza sygnał sterujący u(t) (w tym przypadku % wypełnienia PWM grzałki) na podstawie uchybu regulacji e(t), definiowanego jako różnica między temperaturą zadaną (Tzad) a mierzoną (Tm)
e(t) = Tzad − Tm

Sygnał sterujący jest sumą trzech składowych: u(t) = P(t) + I(t) + D(t) = Kp ∗ e(t) + Ki ∫ e(τ)

t

0

dτ + Kd

de(t)
dt
Gdzie:
Kp, Ki, Kd – nastawy regulatora

Działanie poszczególnych członów:

- Człon Proporcjonalny (P): Sygnał wejściowy jest wprost proporcjonalny do obecnego błędu, jeśli temperatura jest daleka od celu, człon P generuje dużą moc grzania, w miarę zbliżania się do celu, moc ta maleje.
- Sam człon P, nie jest w stanie wyeliminować błędu całkowicie. Przy małej różnicy temperatur, moc dostarczana przez człon P może być mniejsza niż straty ciepła do otoczenia, co prowadzi do powstania uchybu ustalonego
- Człon Całkujący (I): Jego zadaniem jest sumowanie uchybów w czasie. Jeśli przez dłuższy czas temperatura utrzymuje się poniżej wartości zadanej, całka błędu narasta, zwiększając sygnał sterujący
- Zbyt duże wzmocnienie Ki może doprowadzić do oscylacji o niskiej częstotliwości

- Człon Różniczkujący (D): Reaguje nie na wartość błędu, ale na prędkość jego zmian (pochodną). Jeśli temperatura rośnie bardzo szybko, człon D generuje ujemny sygnał sterujący, redukując moc grzania jeszcze zanim temperatura osiągnie cel.
- Zapobiega przeregulowaniu- sytuacji, w której temperatura przestrzeliwuje wartość zadaną po szybkim nagrzewaniu.

Procedura doboru nastaw
W projekcie wykorzystano zaimplementowaną w oprogramowaniu Klipper procedurę auto kalibracji PID, która opiera się na metodzie przekaźnikowej:
1. Wymuszenie oscylacji: Algorytm tymczasowo przejmuje kontrolę nad grzałką, sterując nią w trybie dwustawnym (100% mocy, gdy temperatura spadnie poniżej progu, 0% gdy wzrośnie)
2. Pomiary: System mierzy amplitudę i okres powstałych oscylacji temperatury
3. Obliczenia: Na podstawie charakterystyki oscylacji, algorytm wyznacza parametry krytyczne układu (wzmocnienie krytyczne i okres drgań) a następnie, korzystając z reguł Zieglera-Nicholsa, wylicza optymalne nastawy PID

Rys. 87.Budowa grzałki patronowej szeroko stosowanej w druku 3D. Źródło: [54].

Układ chłodzenia
Efektywne zarządzanie temperaturą wykracza poza samo grzanie. System wyposażono w trzy wentylatory sterowane sygnałem PWM.
- Wentylator chłodzący radiator głowicy: Zapobiega zjawisku „pełzania ciepła”, które mogłoby doprowadzić do spuchnięcia filament przed strefą topnienia i zablokowania ekstrudera
- Dwa wentylatory chłodzące wydruk- Chłodzą one wytłoczony materiał, tak aby zdążył on zastygnąć zanim nałożona zostanie kolejna warstwa

Wentylatory dobrane zostały zgodnie ze specyfikacją projektu głowicy Dragon BurnerV8

System poziomowania i bazowania:
Sonda KlickyNG [42] – W projekcie zrezygnowano z popularnych rozwiązań komercyjnych na rzecz projektu open-source -KlickyNG. Decyzja ta wynika z analizy wad komercyjnych rozwiązań w kontekście druku wysokotemperaturowego i szybkiego.
- Budowa: Sonda składa się z korpusu wyposażonego w mikrostyk oraz magnesy neodymowe. Podczas normalnej pracy sonda jest odczepiona i spoczywa w doku. Podczas pomiaru głowica podjeżdża do doku, magnesy chwytają sondę, a mikrostyk zostaje wpięty w obwód elektryczny
- Zasada działania: Mikrostyk działa w trybie NC. Oznacza to, że obwód jest ciągły, a dotknięcie stołu powoduje jego przerwanie. Takie rozwiązanie jest bezpieczniejsze – w przypadku urwania przewodu drukarka natychmiast wykryje błąd i zatrzyma ruch, zamiast uderzyć głowicą w stół.

Analiza porównawcza:

- KlickyNG a czujnik indukcyjny: czujniki indukcyjne cechują się dryfem temperaturowym- odczyt odległości zmienia się wraz z nagrzewaniem się czujnika od stołu. W zamkniętej komorze jest to zjawisko niepożądane, wymagające programowej kompensacji. Sonda KlickyNG jako układ mechaniczny, jest niewrażliwa na temperaturę oraz rodzaj powierzchni stołu, podczas gdy czujniki indukcyjne wymagają podłoża ferromagnetycznego
- KlickyNG a BLTouch: Czujnik BLTouch jest na stałe zamontowany przy głowicy, zwiększa to masę wózka, w drukarce typu High-Speed, każda redukcja masy jest pożądana. Sonda KlickyNG jest dokowalna i podczas druku spoczywa na ramie.
- KlickyNG a skanery wiroprądowe (Beacon): Nowoczesne czujniki Beacon oferują niezwykle szybkie próbkowanie w trybie ciągłym, tworząc mapę stołu w kilka sekund. Jest to rozwiązanie znacznie droższe i podobnie jak BLTouch, stanowi stałe obciążenie głowicy.

Bazowanie bezczujnikowe:
W osi X/Y wyeliminowano fizyczne wyłączniki krańcowe, wykorzystując funkcję sterowników TMC5160 o nazwie StallGuard2TM.
Każdy silnik krokowy podczas obrotu działa również jako prądnica, generując siłę przeciw elektromotoryczną, która przeciwdziała napięciu zasilania. W momencie mechanicznego zablokowania karetki o ramę drukarki (koniec osi), wirnik zatrzymuje się, a siła przeciw elektromotoryczna spada gwałtownie do zera. Powoduje to nagły wzrost prądu w uzwojeniach i zmianę przesunięcia fazowego między prądem a napięciem.
Sterownik TMC5160 w czasie rzeczywistym analizuje obciążenie silnika i zwraca wartość bezwymiarową. Podczas konfiguracji definiuje się próg czułości tej wartości, gdy wartość odczytana spadnie poniżej tego progu, mikrokontroler interpretuje to jako fizyczną kolizję i natychmiast zatrzymuje silnik, uznając aktualną pozycję za punkt zerowy.

Bazowanie osi Z:
O ile w przypadku lekkiej osi X/Y zastosowanie bazowania bez czujnikowego jest rozwiązaniem optymalnym, o tyle dla osi Z jest to zły pomysł. Napęd osi Z realizowany jest przez przekładnie śrubowe, które charakteryzują się znacznym przełożeniem siły. W przeciwieństwie do napędu paskowego, który przy blokadzie wózka, może bezpiecznie przeskoczyć na zębach, śruba pociągowa działa jak prasa. Próba bazowania bez czujnikowego w osi Z polegałaby na celowym doprowadzeniu do kolizji dyszy ze stołem roboczym, aby sterownik wykrył skok obciążenia. Stanowi to ogromne ryzyko uszkodzeń mechanicznych, dodatkowo oś Z jest stale obciążona masą stołu roboczego, to obciążenie zaburza odczyty wartości siły przeciw elektromotorycznej przez sterownik, utrudniając precyzyjne wyznaczenie progu czułości.

Implementacja wirtualnej krańcówki:
W projektowanym urządzeniu zastosowano koncepcję Virtual Endstop, w której rolę fizycznego wyłącznika krańcowego pełni sonda KlickyNG. Oznacza to, że „zerem” logicznym dla osi Z nie jest punkt na ramie drukarki, lecz fizyczna powierzchnia stołu roboczego.

Procedura bazowania przebiega w ściśle określonej sekwencji:

1. Bazowanie płaszczyzny X/Y
2. Pobieranie sondy
3. Bazowanie Z
4.
Korzyści wynikające z zastosowanego rozwiązania:
- Referencja do powierzchni druku: Punkt Z=0 jest zawsze na powierzchni stołu, niezależnie od grubości zastosowanej podkładki (np. zmiana płyty PEI na szkło nie wymaga rekalibracji)
- Automatyzacja: System eliminuje konieczność ręcznej regulacji śrubami dystansowymi przy zmianie dyszy lub elementów głowicy
- Prostota: Dzięki takiemu rozwiązaniu, nie ma konieczności montażu czujników krańcowych

Akcelerometr i kompensacja drgań:
Jednym z głównych ograniczeń prędkości w druku 3D nie jest moc silników, lecz sztywność ramy i elastyczność pasów napędowych. Układ kinematyczny drukarki, składający się z mas i elementów sprężystych (pasy zębate), tworzy klasyczny oscylator harmoniczny. Podczas gwałtownych przyspieszeń, wzbudzane są częstotliwości rezonansowe, które objawiają się na wydruku jako artefakty przy krawędziach modelu. Aby temu zapobiec, w projekcie wykorzystano technikę sterowania zwaną Input Shaping, która wymaga precyzyjnej identyfikacji parametrów dynamicznych maszyny za pomocą akcelerometru.

Budowa i zasada działania czujnika ADXL345:
Jako sensor pomiarowy wybrano układ ADXL345. Jest to 3 osiowy akcelerometr wykonany w technologii MEMS (Micro-Electro-Mechanical System)
Zasada pomiaru: Wewnątrz struktury krzemowej czujnika znajduje się zawieszona masa bezwładna, zamocowana na sprężystych belkach polikrzemowych. Masa ta porusza się pomiędzy nieruchomymi okładzinami kondensatora, tworząc układ kondensatorów różnicowych.
1. Gdy na czujnik działa przyspieszenie, masa bezwładna ulega przemieszczeniu
2. Zmiana odległości między okładzinami powoduje zmianę pojemności elektrycznej układu
3. Zintegrowany układ elektroniczny przetwarza tę zmianę pojemności na sygnał napięciowy a następnie na sygnał cyfrowy reprezentujący wartość przyspieszenia w osi X/Y

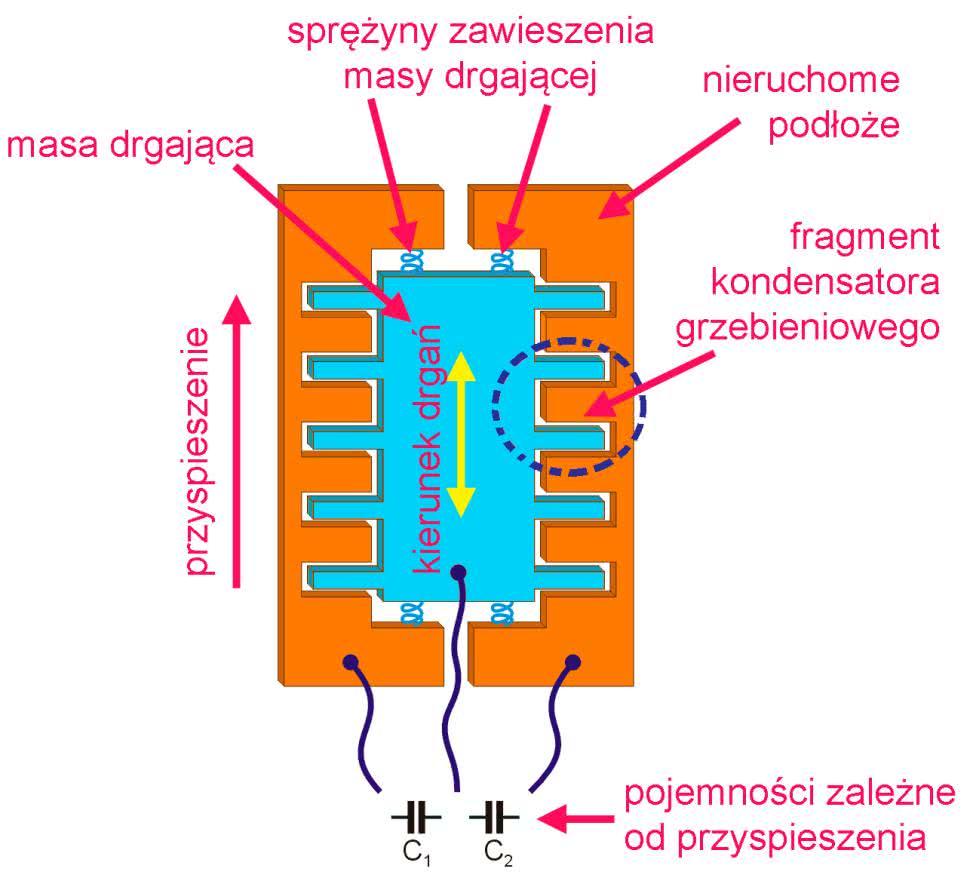
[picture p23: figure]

Rys. 88. Schemat budowy pojemnościowego akcelerometru MEMS. Źródło: [27].

Rys. 89. Schemat elektryczny pojemnościowego akcelerometru MEMS. Źródło: [52].

Interpretacja danych i analiza rezonansu
Proces kalibracji w środowisku Klipper polega na wykonaniu testu częstotliwościowego. Sterownik generuje serię ruchów oscylacyjnych o narastającej częstotliwości dla każdej osi.
W tym czasie akcelerometr zamontowany na głowicy rejestruje rzeczywiste wibracje układu. Surowe dane z domeny czasu są przetwarzane przez oprogramowanie przy użyciu transformaty Fouriera.
Wynikiem analizy jest wykres PSD (Power Spectral Density), który pokazuje, przy jakich częstotliwościach układ wpada w rezonans. Piki na wykresie wskazują częstotliwości własne ramy, które należy wyeliminować.

Zasada działania algorytmu Input Shaping [48]:
Input Shaping to technika sterowania w pętli otwartej. Nie koryguje ona błędów w trakcie ruchu, lecz modyfikuje sygnał wejściowy tak, aby nie wzbudzał on drgań własnych maszyny
Działanie algorytmu opiera się na łączeniu sygnału sterującego z sekwencją impulsów o określonych opóźnieniach i amplitudach.
Wysłanie jednego impulsu sterującego wywołuje drgania o określonym okresie T. Algorytm Input Shaping, dzieli ten jeden silny impuls na dwa (lub więcej) mniejsze impulsy:
1. Impuls pierwszy: Inicjuje ruch, wzbudzając jednocześnie drgania rezonansowe
2. Impuls drugi: Wysyłany jest z opóźnieniem wynoszącym dokładnie połowę okresu drgań własnych (0,5T)
3.
Ponieważ drugi impuls przesunięty w fazie o 180°, drgania przez niego wywołane nakładają się na drgania z pierwszego impulsu. Zachodzi zjawisko destruktywnej

interferencji- fale drgań znoszą się wzajemnie, a wózek zatrzymuje się w zadanej pozycji bez oscylacji końcowych.

Rys. 90. Zasada działania Input Shaping – znoszenie się fal drgań. Źródło: [48].

Rys. 91. Porównanie odpowiedzi układu na skok jednostkowy: bez kompensacji (linia ciągła) i z włączonym Input Shaping (linia przerywana). Źródło: [49].

Detekcja obecności materiału
W projekcie zastosowano czujnik oparty na mikroprzełączniku, dzięki temu drukarka jest w stanie zatrzymać druk i powiadomić użytkownika, gdy zabraknie materiału drukującego.

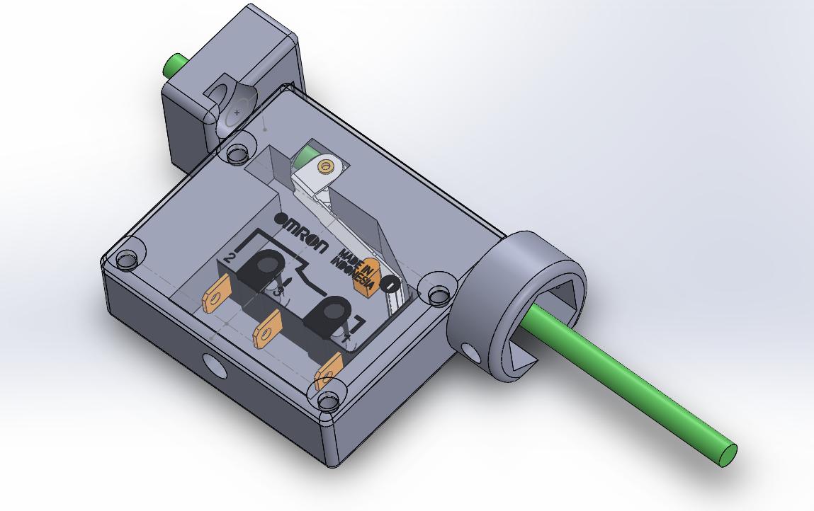
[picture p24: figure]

Rys. 92. Wizualizacja czujnika filamentu opartego na mikroprzełączniku. Źródło:[28]

Zasada działania:
Filament przeprowadzany jest przez kanał w obudowie czujnika, mechanicznie naciskając dźwignię przełącznika. Dopóki materiał znajduje się w torze podawania, obwód elektryczny pozostaje zamknięty (lub otwarty, zależnie od konfiguracji). W momencie skończenia się materiału, dźwignia zostaje zwolniona, zmieniając stan logiczny na wejściu mikrokontroler

### 5. Konfiguracja oprogramowania sterującego

### 5.1 Ekosystem programowy

Wydajność współczesnej drukarki 3D zależy nie tylko od konstrukcji mechanicznej i układu elektrycznego, ale przede wszystkim od wydajności i stabilności oprogramowania sterującego. Ze względu na wysokie wymagania obliczeniowe kinematyki CoreXY oraz konieczność implementacji zaawansowanych algorytmów kompensacji drgań, w projekcie zastosowano architekturę rozproszoną opartą na systemie Klipper [31].

Architektura rozproszona

Tradycyjne sterowniki drukarek 3D realizują wszystkie zadania na jednym mikrokontrolerze: planowanie ruchu, generowanie sygnałów krokowych, obsługę interfejsu użytkownika oraz komunikację. Przy wysokich prędkościach i złożonej geometrii moc obliczeniowa mikrokontrolera staje się wąskim gardłem, prowadząc do błędów taktowania silników.

Klipper rozwiązuje ten problem poprzez separację logiki na dwie niezależne jednostki:

1. Jednostka nadrzędna (Host) – Raspberry Pi 4B
a. Klipper Host (klippy.py) – główny proces działający w tle systemu Linux. Odpowiada za parsowanie plików G-code, obliczanie kinematyki odwrotnej CoreXY oraz zaawansowane algorytmy (Input Shaping, Pressure Advance). Klippy analizuje ścieżkę narzędzia z wyprzedzeniem czasowym, kompresuje instrukcje i przesyła je do mikrokontrolera w formie bloków binarnych.
b. Moonraker [32] (API Server) – serwer HTTP/WebSocket udostępniający interfejs programistyczny dla aplikacji zewnętrznych. Zarządza bazą danych plików, historią wydruków oraz aktualizacjami oprogramowania.
c. Mainsail [33] (Web UI) – interfejs graficzny uruchamiany w przeglądarce. Wizualizuje w czasie rzeczywistym parametry pracy drukarki (temperatura, pozycja, prędkość) oraz umożliwia zdalne sterowanie.
d. Crowsnest – usługa systemowa odpowiedzialna za przechwytywanie i udostępnianie strumienia wideo z kamery USB w sieci lokalnej.

### 2. Jednostka wykonawcza (MCU) – BTT Octopus Max EZ

a. Klipper Firmware – niskopoziomowy kod w języku C wgrany do pamięci Flash mikrokontrolera. Jego zadaniem jest wyłącznie odbiór skompresowanych bloków danych od Hosta, ich dekompresja i precyzyjne wykonanie w ściśle określonym czasie. Dzięki buforowaniu poleceń, nawet chwilowe spowolnienie systemu operacyjnego na Raspberry Pi nie wpływa na płynność ruchu silników.

Taka separacja obowiązków pozwala na wykonywanie obliczeń numerycznych o wysokiej złożoności (np. transformacja Fouriera dla analizy rezonansów) na jednostce o dużej mocy obliczeniowej, przy jednoczesnym zachowaniu deterministycznego taktowania impulsów na poziomie mikrokontrolera.

### 5.2 Konfiguracja układu kinematycznego

Definicja typu kinematyki:
Podstawą poprawnej pracy urządzenia jest precyzyjne odwzorowanie jego fizycznej budowy w oprogramowaniu sterującym. W pliku `printer.cfg` zdefiniowano typ kinematyki oraz sztywne limity bezpieczeństwa:

Implementacja:

```ini
[printer]
kinematics: corexy
max_velocity: 500
max_accel: 20000
max_z_velocity: 15
max_z_accel: 300
square_corner_velocity: 8.0
```

Parametr `kinematics: corexy` informuje sterownik o konieczności zastosowania odpowiednich równań transformacji współrzędnych. Bez tej deklaracji system sterowałby silnikami w układzie kartezjańskim, co w konstrukcji CoreXY jest fizycznie niemożliwe i doprowadziłoby do zablokowania mechaniki.

Wartości prędkości i przyspieszeń stanowią górną granicę, której maszyna nie przekroczy niezależnie od poleceń w pliku G-code, chroniąc konstrukcję przed uszkodzeniem mechanicznym.

Konfiguracja osi X/Y (AWD)

Ze względu na zastosowanie układu napędowego typu AWD (All Wheel Drive), w którym każda pętla pasów napędzana jest przez dwa silniki, konfiguracja wymaga zdefiniowania par sterujących:

- [stepper_x]` oraz `[stepper_x1] – para odpowiedzialna za pierwszą pętlę paska
- [stepper_y]` oraz `[stepper_y1] – para odpowiedzialna za drugą pętlę paska

Parametr ‘rotation_distance’
Środowisko Klipper definiuje ruch w oparciu o parametr `rotation_distance`, który określa fizyczną drogę liniową (w milimetrach) pokonaną przez element wykonawczy podczas jednego pełnego obrotu wału silnika. Dla osi X/Y zastosowano:

```
rotation_distance = 40 mm
```

Synchronizacja silników AWD

W systemie Klipper synchronizacja silników AWD nie odbywa się na poziomie elektrycznym, lecz programowym. Wewnętrzna logika operuje na pojęciu „szyn wirtualnych". Podczas konfiguracji przypisanie wielu sterowników do tej samej osi powoduje, że Klipper oblicza identyczne listy czasowe kroków dla obu silników pary i wysyła je do mikrokontrolera.

Ponieważ oba piny sterujące obsługiwane są przez ten sam mikrokontroler korzystający z jednego oscylatora kwarcowego, zmiana stanu obu pinów następuje w tym samym cyklu maszynowym, zapewniając zerowy błąd synchronizacji.

Implementacja

```ini
# Główny silnik X

[stepper_x]
step_pin: PA8
dir_pin: !PC7
enable_pin: !PC9
microsteps: 32
rotation_distance: 40
full_steps_per_rotation: 200
endstop_pin: tmc5160_stepper_x1:virtual_endstop position_min: 0
position_endstop: 0
position_max: 321
homing_speed: 60
homing_retract_dist: 0

# Dodatkowy silnik X

[stepper_x1]
step_pin: PC13
dir_pin: !PC14
enable_pin: !PE6
rotation_distance: 40
microsteps: 32
full_steps_per_rotation: 200

# Główny silnik Y

[stepper_y]
step_pin: PB8
dir_pin: !PB9
enable_pin: !PB7
microsteps: 32
rotation_distance: 40
full_steps_per_rotation: 200
endstop_pin: tmc5160_stepper_y:virtual_endstop position_min: 0

position_endstop: 265
position_max: 265
homing_speed: 80
homing_retract_dist: 0

# Dodatkowy silnik Y

[stepper_y1]
step_pin: PE4
dir_pin: !PE5
enable_pin: !PE3
rotation_distance: 40
microsteps: 32
full_steps_per_rotation: 200
```
Przyjęto strategię bazowania do tylnego prawego narożnika (X=321, Y=265). Punkt (0,0) znajduje się w lewym przednim rogu stołu. Zamiast fizycznych krańcówek zastosowano wirtualne ‘krańcówki’ realizowane przez sterowniki TMC5160 (`virtual_endstop`), co umożliwia bazowanie bezczujnikowe (Sensorless Homing).

Konfiguracja osi Z

Układ podnoszenia stołu realizowany jest przez trzy niezależne silniki sprzężone ze śrubami trapezowymi (skok 8mm):

```
rotation_distance = 8 mm
```
Implementacja:
```ini
# Silnik Z

[stepper_z]
step_pin: PD3
dir_pin: !PD2
enable_pin: !PD4
microsteps: 32
rotation_distance: 8
endstop_pin: probe:z_virtual_endstop position_min: -10
position_max: 270
homing_speed: 8.0
second_homing_speed: 3.0
homing_retract_dist: 6.0

# Silnik Z1

[stepper_z1]
step_pin: PG15
dir_pin: !PB3
enable_pin: !PD5
microsteps: 32
rotation_distance: 8

# Silnik Z2

[stepper_z2]
step_pin: PB5
dir_pin: !PB4
enable_pin: !PB6
microsteps: 32
rotation_distance: 8
```

Wartość `position_min: -10` stanowi margines bezpieczeństwa niezbędny do kalibracji pierwszej warstwy, pozwalając dyszy na zjazd nieco poniżej teoretycznego zera w celu kompensacji nierówności stołu.

Konfiguracja sterowników TMC [29]

Osie X/Y – TMC5160 (48V, tryb SpreadCycle)
Dla osi głównych zastosowano sterowniki TMC5160 zasilane napięciem 48V. Wybrany tryb SpreadCycle zapewnia maksymalny moment obrotowy i szybką reakcję na zmiany wektora ruchu, co jest kluczowe dla synchronizacji czterech silników przy gwałtownych manewrach.
Objaśnienie trybu SpreadCycle:
Technika „chopper" polega na szybkim włączaniu i wyłączaniu wysokiego napięcia zasilania (48V) w celu regulacji rzeczywistego prądu w uzwojeniach. SpreadCycle działa w pętli sprzężenia zwrotnego – sterownik w każdym cyklu zegara mierzy rzeczywisty prąd i porównuje go z wartością zadaną, automatycznie dobierając czas trwania impulsu.

Przyjęto prąd roboczy 1.2A RMS (wartość szczytowa ~1.7A), co stanowi 85% prądu znamionowego silnika NEMA17. Podczas bazowania prąd jest tymczasowo obniżany do 0.65A/0.8A (w zależności od osi), aby zapobiec uszkodzeniu mechanicznemu w momencie wykrywania pozycji krańcowej.

Implementacja:
```ini
[tmc5160 stepper_x]
cs_pin: PG8
spi_bus: spi4
sense_resistor: 0.075
run_current: 0.100 # Tymczasowe obniżenie podczas bazowania stealthchop_threshold: 0

[tmc5160 stepper_x1]
cs_pin: PG14
spi_bus: spi4
sense_resistor: 0.075
diag1_pin: ^!PF0
driver_SGT: 1 | # Czułość bezczujnikowego bazowania
run_current: 0.650
stealthchop_threshold: 0

[tmc5160 stepper_y]
cs_pin: PG11
spi_bus: spi4
sense_resistor: 0.075
diag1_pin: ^!PF3
driver_SGT: 1
run_current: 0.800
stealthchop_threshold: 0

[tmc5160 stepper_y1]
cs_pin: PG13
spi_bus: spi4
run_current: 0.100
stealthchop_threshold: 0
```
Oś Z – TMC2209 (24V, tryb StealthChop)

Układ napędowy osi Z pracuje w zupełnie innych warunkach – ruchy są rzadkie i powolne. Przyjęto prąd **0.8A RMS** (40% wartości znamionowej), co przy dużym przełożeniu mechanicznym śruby trapezowej jest wystarczające i zapobiega nagrzewaniu się silników.

Objaśnienie trybu StealthChop:
W klasycznym sterowaniu „chopper" gwałtowne włączanie i odcinanie prądu powodują powstawanie tętnień, które poprzez zjawisko magnetostrykcji (mikro-odkształcenia rdzenia) generują charakterystyczne buczenie. StealthChop eliminuje to poprzez zmianę paradygmatu – zamiast mierzyć prąd w każdym cyklu, sterownik „uczy się" charakterystyki silnika podczas auto-kalibracji i generuje gładką falę napięciową, eliminując gwałtowne skoki prądu.

Implementacja:

```ini
[tmc2209 stepper_z]
uart_pin: PD7
interpolate: False
run_current: 0.8
sense_resistor: 0.110
stealthchop_threshold: 0

[tmc2209 stepper_z1]
uart_pin: PG9
interpolate: False
run_current: 0.8
sense_resistor: 0.110
stealthchop_threshold: 0

[tmc2209 stepper_z2]
uart_pin: PG10

interpolate: False
run_current: 0.8
sense_resistor: 0.110
stealthchop_threshold: 0
```
Rozdzielczość pozycjonowania
Przyjęcie mikrokroków= 32 dla wszystkich osi zapewnia wysoką precyzję teoretyczną:
- Dla osi X/Y przy ‘rotation_distance = 40’
RozdzielczośćXY =

40mm
200 ∗ 32 = 0,00625mm
- Dla osi Z przy ‘rotation_distance =8’ RozdzielczośćZ =

8mm
200 ∗ 32 = 0,00125mm

Konfiguracja ekstrudera:

```ini
[extruder]
step_pin: PA10
dir_pin: PA9
enable_pin: !PA15
microsteps: 16
rotation_distance: 3.6
nozzle_diameter: 0.400
filament_diameter: 1.750
heater_pin: PF6 | # Wyjście HE0
sensor_pin: PB0 | # Wejście T0
sensor_type: PT1000
pullup_resistor: 2200
min_temp: 0
max_temp: 250

[tmc2209 extruder]
uart_pin: PD6
interpolate: False
run_current: 0.600
sense_resistor: 0.110
stealthchop_threshold: 999999

### 5.3 Parametryzacja procesu druku

Algorytm Pressure Advance [50]
W szybkim druku 3D głównym problemem jakościowym jest elastyczność filamentu. W układzie Direct Drive stopione tworzywo zachowuje się jak ciecz nienewtonowska – podczas przyspieszania głowicy ciśnienie w dyszy narasta z opóźnieniem, powodując niedolanie na początku linii. Podczas hamowania zgromadzone ciśnienie powoduje nadlanie w narożnikach.

Algorytm Pressure Advance modeluje zachowanie cieczy, wprowadzając korektę ruchu silnika ekstrudera zgodnie ze wzorem:

Vekstruder = Vdysza + PA ∗ A
Gdzie:
V_dysza – zadana prędkość wypływu
PA – współczynnik Pressure Advance (typowo 0.02-0.04 s dla Sherpa Mini)
A – aktualne przyspieszenie głowicy

W praktyce oznacza to, że silnik ekstrudera „dopycha" materiał podczas przyspieszania lub wykonuje szybką retrakcję podczas hamowania, zanim głowica się zatrzyma.

Rys. 93. Wpływ algorytmu Pressure Advance na jakość narożników: po lewej (bez PA), po prawej (z PA). Źródło: [51].

Algorytm Input Shaping [49]
Implementacja programowa techniki Input Shaping w środowisku Klipper opiera się na automatycznej analizie widmowej sygnałów zarejestrowanych przez akcelerometr ADXL345. Celem procedury jest dobranie matematycznego modelu filtra, który zminimalizuje rezonanse przy zachowaniu jak najmniejszego wpływu na geometrię ścieżki.

Klipper weryfikuje następujące typy filtrów:

- ZV (Zero Vibration) – najbardziej podstawowy, wymaga idealnego trafienia w częstotliwość rezonansową. Oferuje najmniejsze wygładzenie, ale jest wrażliwy na zmiany masy wózka.
- MZV (Modified Zero Vibration) – zmodyfikowana wersja ZV, oferująca szersze pasmo tłumienia. Najczęściej wybierany kompromis dla sztywnych konstrukcji CoreXY.
- EI (Extra Insensitive) – filtr o szerszym „oknie" tłumienia, bardziej odporny na niewielkie zmiany częstotliwości własnych, jednak wprowadzający większe wygładzenie.

- 2HUMP_EI / 3HUMP_EI – filtry wielogarbne, stosowane w układach o bardzo złożonej charakterystyce drganiowej. Ich wadą jest zaokrąglanie narożników wydruku.

Algorytm decyzyjny Klippera automatycznie sugeruje filtr, który redukuje wibracje poniżej akceptowalnego progu, generując jednocześnie najmniejsze wygładzenie. Wyniki kalibracji są zapisywane w sekcji `[input_shaper]` pliku konfiguracyjnego, osobno dla osi X i Y.

### 5.4 Procedury automatyczne

W celu automatyzacji obsługi urządzenia wykorzystano funkcjonalność programowalnych makr G-Code. System Klipper pozwala na definiowanie własnych funkcji oraz nadpisywanie standardowych komend, wprowadzając do prostego języka G-code elementy logiki programistycznej (zmienne, warunki, pętle).
Makro realizuje następującą sekwencję:

Algorytm bazowania bezczujnikowego [29]:
Wykorzystanie funkcji Sensorless Homing w osiach X/Y wymaga dedykowanej procedury bazowania. Bez odpowiedniego wysterowania bazowanie układu o dużej mocy wiązałoby się z ryzykiem uszkodzenia mechanicznego ramy.
1. Bezpieczne podniesienie Z (aby głowica nie uderzyła w stół podczas ruchu XY)
2. Bazowanie Y z obniżonym prądem (tylko `stepper_y1` aktywny z prądem 0.8A)
3. Bazowanie X z obniżonym prądem (tylko `stepper_x` aktywny z prądem 0.65A)
1. Przywrócenie pełnej mocy (1.2A dla wszystkich silników XY)
2. Bazowanie Z z użyciem sondy KlickyNG

Implementacja:
```ini
[homing_override]
axes: xyz
gcode:
# 1. Konfiguracja prądów

{% set RUN_CURRENT = 1.200 %}
{% set HOME_CURRENT_X = 0.650 %} {% set HOME_CURRENT_Y1 = 0.800 %} {% set HELPER_CURRENT = 0.100 %}

# 2. Bezpieczne podniesienie Z SET_KINEMATIC_POSITION Z=0 G1 Z15 F600

# 3. Bazowanie Y (sensorless)

SET_TMC_CURRENT STEPPER=stepper_y CURRENT={HELPER_CURRENT} SET_TMC_CURRENT STEPPER=stepper_y1 CURRENT={HOME_CURRENT_Y1}
G28 Y

# 4. Bazowanie X (sensorless)

SET_TMC_CURRENT STEPPER=stepper_x CURRENT={HOME_CURRENT_X} SET_TMC_CURRENT STEPPER=stepper_x1 CURRENT={HELPER_CURRENT} G28 X

# 5. Przywrócenie pełnej mocy XY

SET_TMC_CURRENT STEPPER=stepper_x CURRENT={RUN_CURRENT} SET_TMC_CURRENT STEPPER=stepper_x1 CURRENT={RUN_CURRENT} SET_TMC_CURRENT STEPPER=stepper_y CURRENT={RUN_CURRENT} SET_TMC_CURRENT STEPPER=stepper_y1 CURRENT={RUN_CURRENT}

# 6. Bazowanie Z z sondą

G90
ATTACH_PROBE
G1 X152 Y172 F6000
G28 Z
G1 Z10 F600

```
Algorytm automatycznego poziomowania stołu (Z-Tilt)
Dzięki zastosowaniu trzech niezależnych napędów osi Z możliwe jest programowe wypoziomowanie platformy roboczej względem płaszczyzny ruchu głowicy. Wykorzystano wbudowany moduł `[z_tilt]`.

Zasada działania:

1. Definicja modelu – w konfiguracji określono współrzędne fizycznego położenia śrub napędowych oraz odpowiadające im punkty pomiarowe na stole.
2. Pomiar – sonda KlickyNG wykonuje pomiar odległości w trzech punktach.
3. Korekta iteracyjna – algorytm oblicza względne korekty położenia każdej osi Z, proces powtarza się aż różnica wysokości spadnie poniżej progu tolerancji (0.025mm).

Implementacja:

[z_tilt]
z_positions:
-28, -1 | # stepper_z (przód-lewy)
163, 298 | # stepper_z1 (tył-środek)
332, -11 | # stepper_z2 (przód-prawy)

points:
0, 0 | # przód-lewy
163, 255 | # tył-środek
250, 0 | # przód-prawy

speed: 150
horizontal_move_z: 15
retries: 5
retry_tolerance: 0.025

[gcode_macro LEVEL_BED]
description: Wyrównanie stołu - wywołuj zaraz po G28
gcode:
{% if not "xyz" in printer.toolhead.homed_axes %}
{ action_raise_error("Najpierw zbazuj wszystkie osie! Użyj: G28") } {% endif %}

G90
G1 Z20 F600
Z_TILT_ADJUST
G1 Z20 F600
DETACH_PROBE

Mapowanie stołu (Bed Mesh)
Oprócz globalnego poziomowania (Z-Tilt), system potrafi skanować lokalne nierówności stołu i kompensować je dynamicznie podczas druku:

Implementacja:

```ini
[bed_mesh]
speed: 300
horizontal_move_z: 15
mesh_min: 30, 30
mesh_max: 270, 260
probe_count: 5, 5
fade_start: 1.0
fade_end: 10.0 # Po 10mm wysokości korygowanie zanika algorithm: bicubic

[gcode_macro GENERATE_BED_MESH]
description: Pobiera sondę, robi mapę stołu i odkłada sondę gcode:
{% if not "xyz" in printer.toolhead.homed_axes %}
G28
{% endif %}

ATTACH_PROBE
BED_MESH_CALIBRATE PROFILE=default DETACH_PROBE
```

Sekwencja startowa wydruku
Makro `PRINT_START` integruje wszystkie podsystemy w spójną procedurę inicjalizacji.
Implementacja:

```gcode
G28 | # Bazowanie
M190 S[bed_temperature_initial_layer_single] # Czekaj na temperaturę stołu

M109 S[nozzle_temperature_initial_layer] | # Czekaj na temperaturę dyszy
LEVEL_BED | # Poziomowanie Z-Tilt
BED_MESH_PROFILE LOAD=default # załadowanie mapy mesh
G90
G1 Z5 F600
G1 X20 Y40 F6000
G1 Z0.3 F300 | # Linia rozbiegowa
```

Sekwencja zakończenia wydruku
W celu zakończenia druku zastosowano makro ‘PRINT_END’, które jest wywoływane automatycznie po wykonaniu ostatniej linii G-Code.

Implementacja:
```gcode
M104 S0 | # Wyłącz grzałkę dyszy
M140 S0 | # Wyłącz grzałkę stołu
G91
G1 Z10 F600 # Podnieś głowicę
G90
G1 X10 Y276 F6000 # Parkuj z tyłu (łatwy dostęp do wydruku)
M84 | # Wyłącz silniki
```

Procedura bezpiecznego wstrzymania (PAUSE)
Standardowa komenda pauzy jedynie zatrzymuje ruch, co skutkuje stopieniem wydruku w miejscu postoju. Zdefiniowano zaawansowane makro realizujące:
1. Zapis stanu (współrzędne, parametry ekstruzji)
2. Parkowanie głowicy poza obszarem roboczym
3. Retrakcję filamentu
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

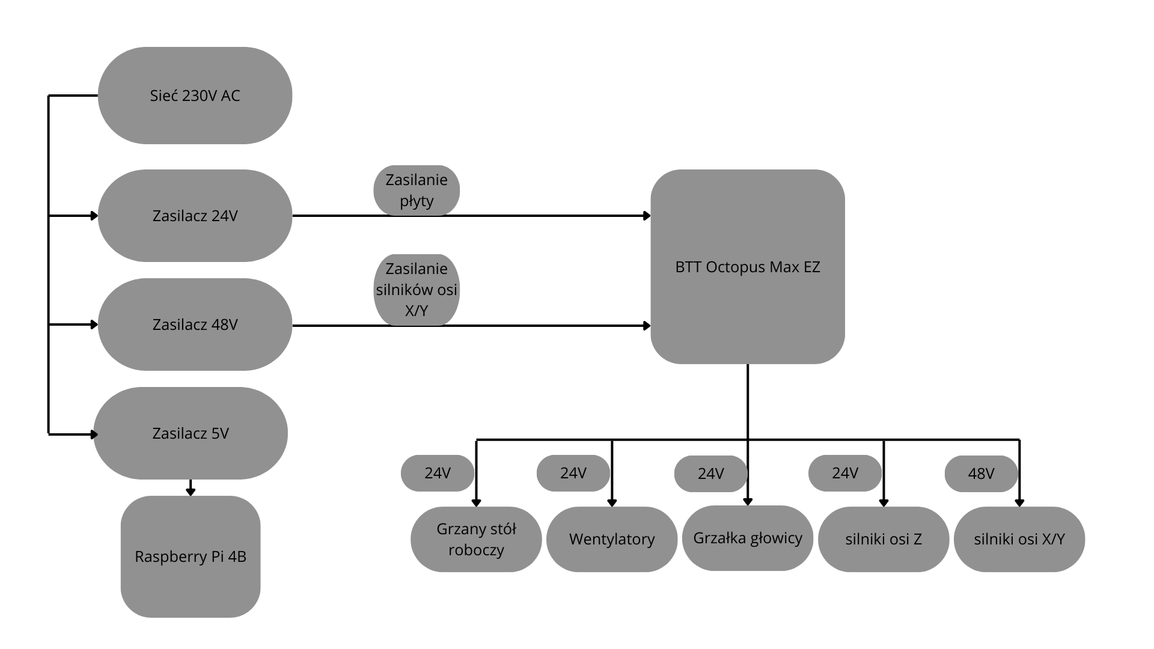
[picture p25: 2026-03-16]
documentation/schemat zasilanie.png

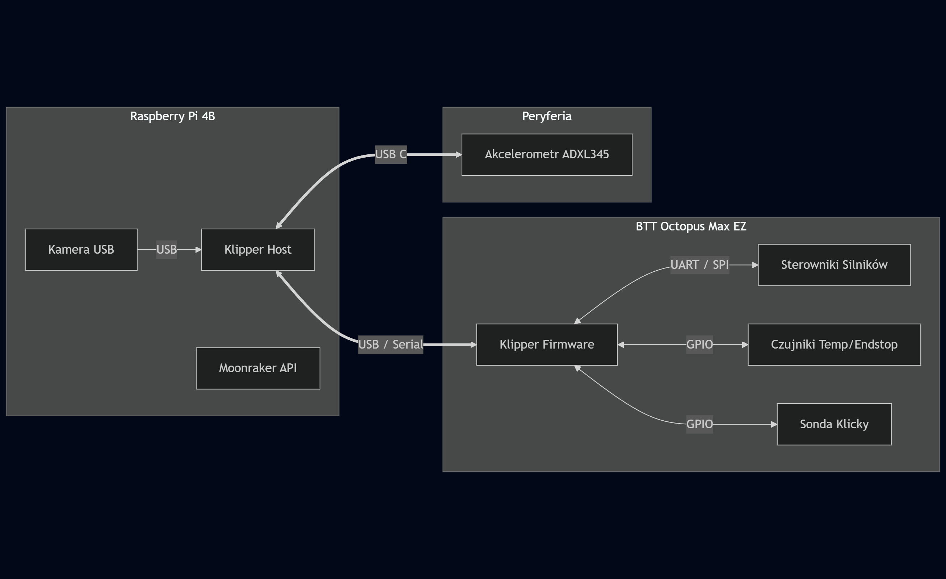
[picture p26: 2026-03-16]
documentation/schemat sterowanie i komunikacja.png

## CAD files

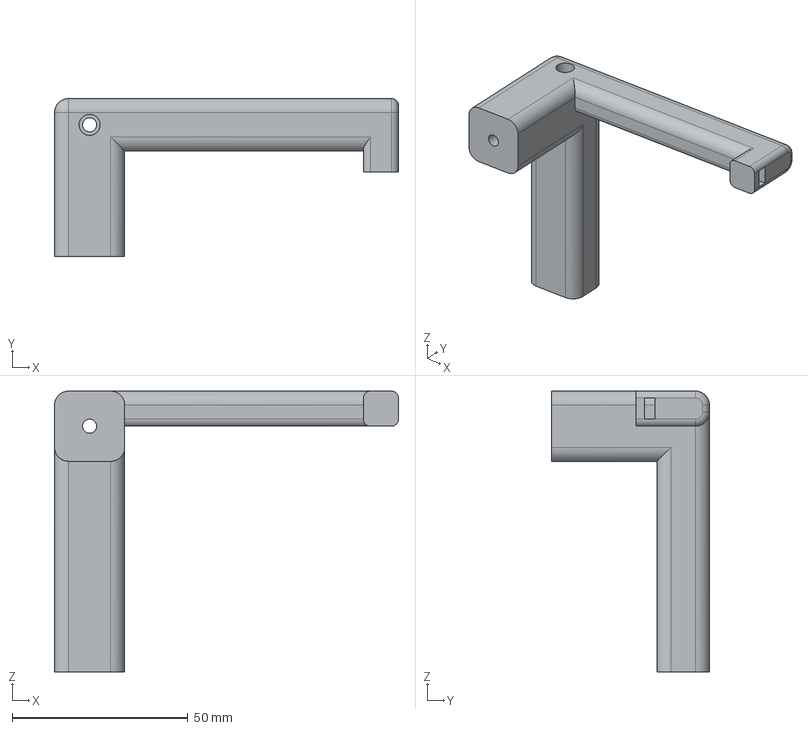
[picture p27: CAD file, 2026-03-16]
CAD/endstop X mounting.step
98.0 x 45.0 x 80.0 mm

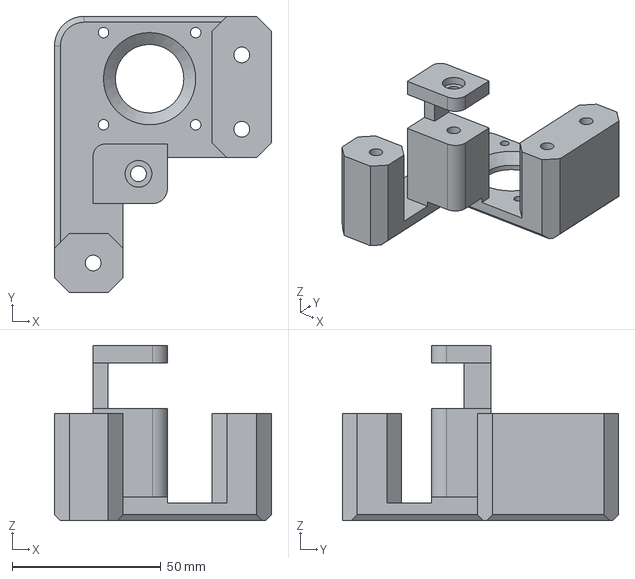
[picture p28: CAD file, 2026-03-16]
CAD/XY motor front right mounting.step
73.0 x 93.0 x 59.0 mm

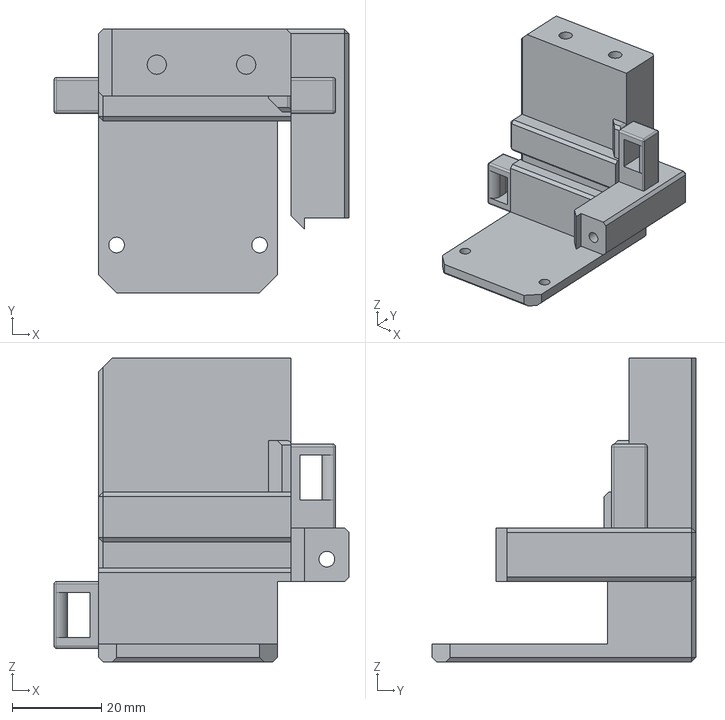
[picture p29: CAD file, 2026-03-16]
CAD/printhead mounting2.step
66.0 x 59.0 x 68.0 mm

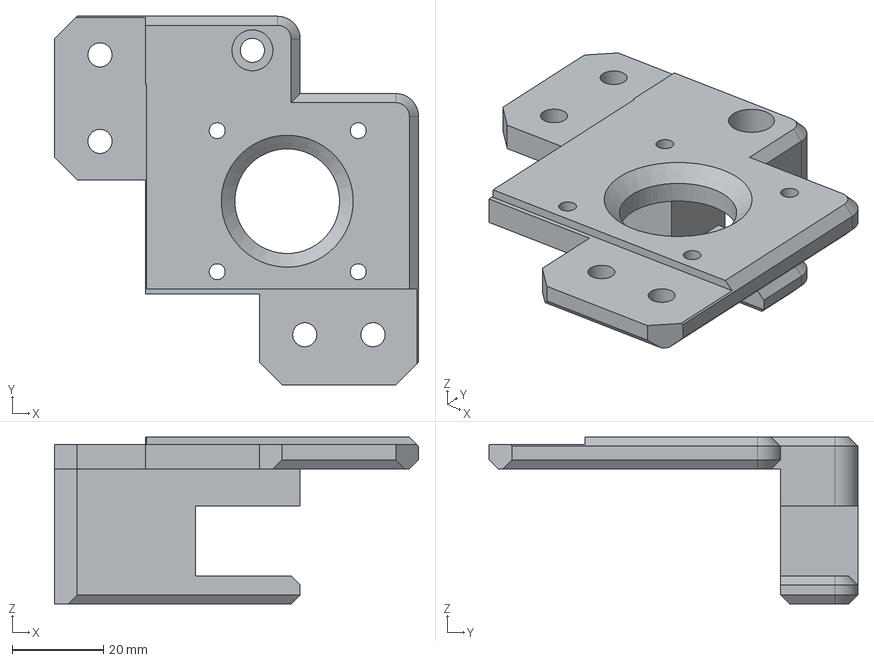
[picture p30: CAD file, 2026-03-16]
CAD/XY motor front-left mounting.step
80.0 x 81.0 x 36.7 mm

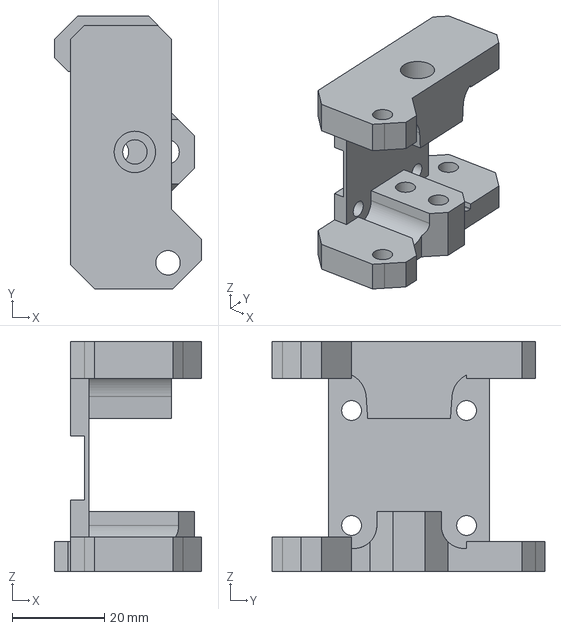
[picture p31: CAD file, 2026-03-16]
CAD/gantry mounting right.step
32.0 x 59.2 x 50.0 mm

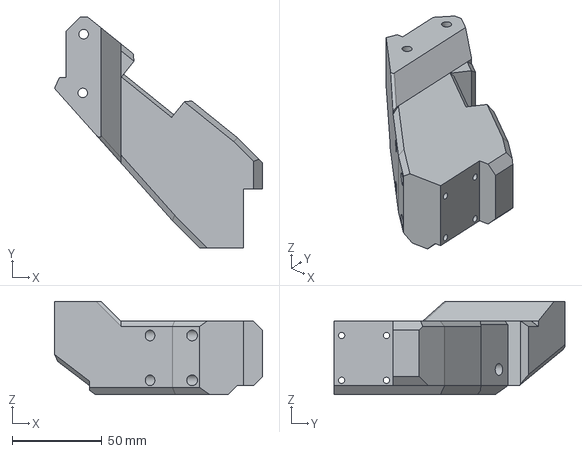
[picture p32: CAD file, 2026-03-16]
CAD/heated bed mounting right.step
116.0 x 128.7 x 52.0 mm

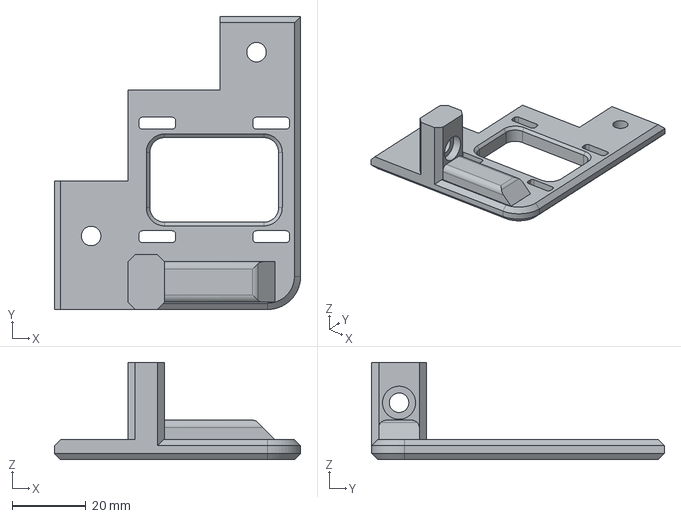
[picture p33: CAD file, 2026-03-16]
CAD/XY motor rear-right mounting.step
67.0 x 79.7 x 26.5 mm

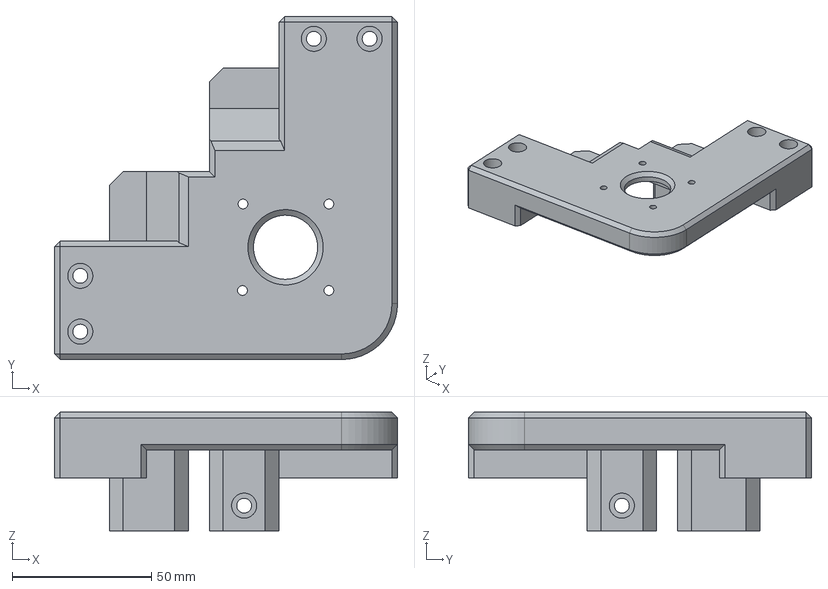
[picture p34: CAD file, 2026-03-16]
CAD/Z motor left mounting.step
123.0 x 123.0 x 42.5 mm

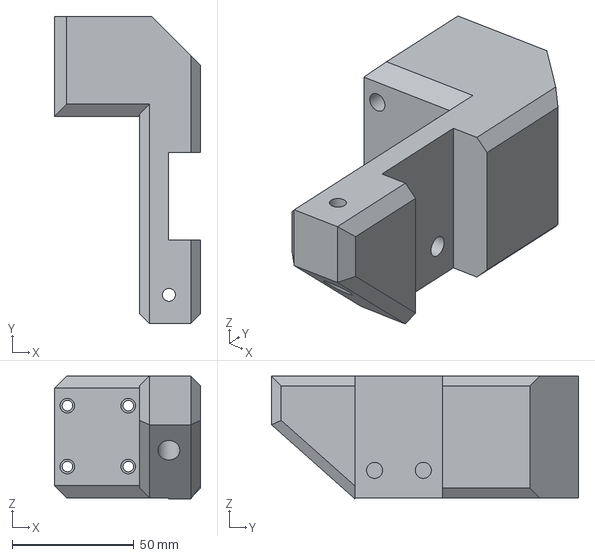
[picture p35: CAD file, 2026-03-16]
CAD/heated bed mounting back.step
60.0 x 126.0 x 50.4 mm

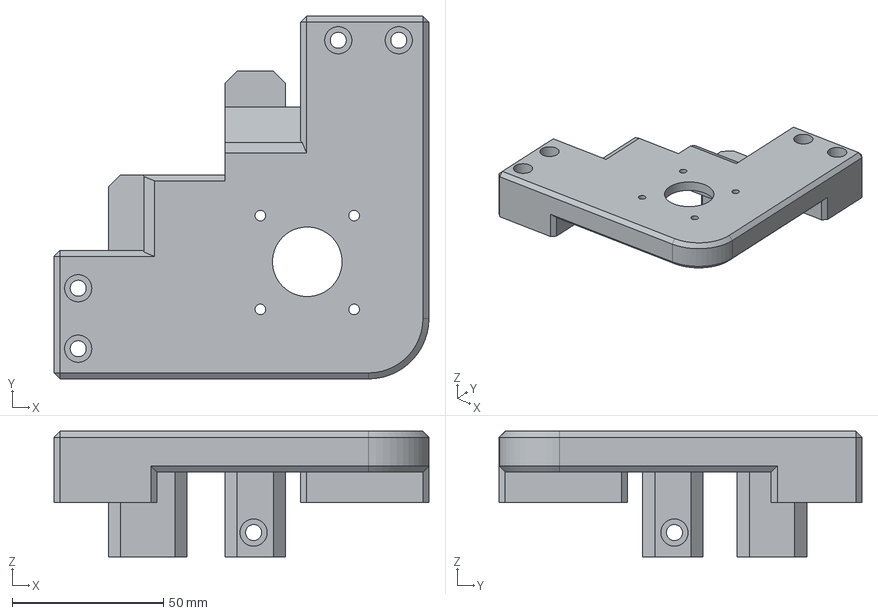
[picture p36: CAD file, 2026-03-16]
CAD/Z motor right mounting.step
124.0 x 120.0 x 41.5 mm

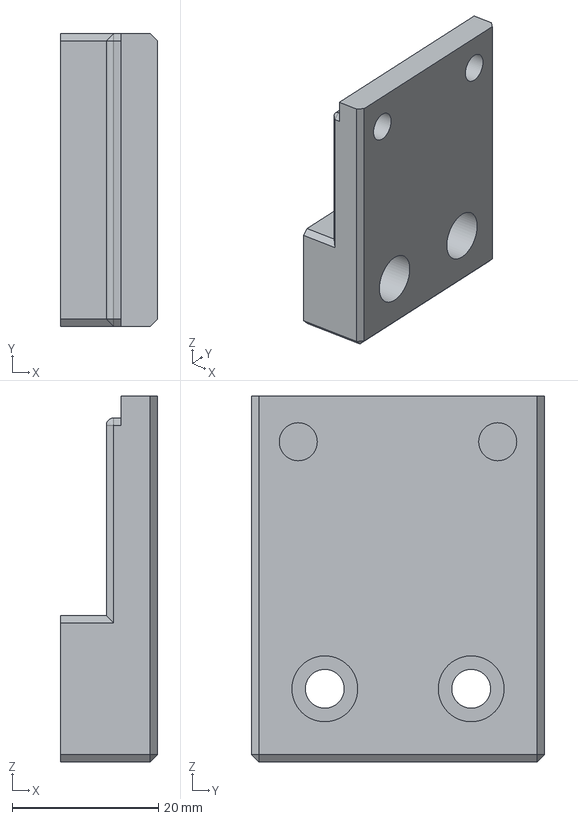
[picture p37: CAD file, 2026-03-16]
CAD/klickyNG dock mounting.step
13.3 x 40.0 x 50.0 mm

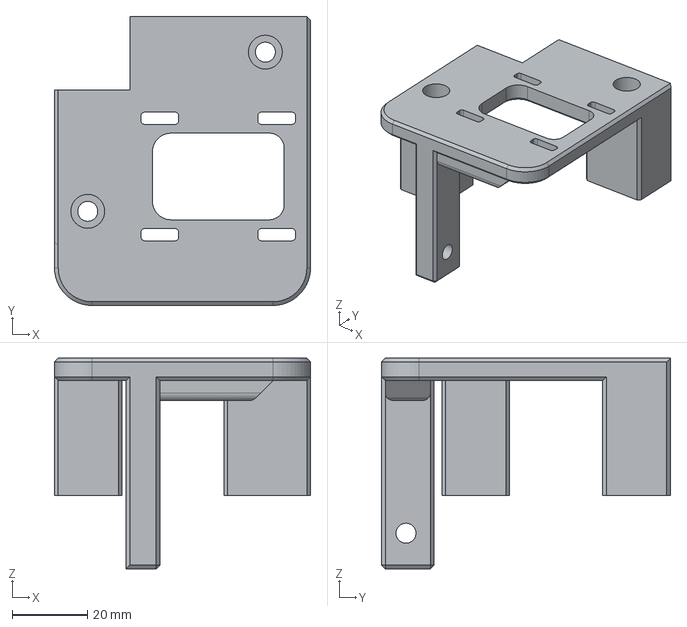
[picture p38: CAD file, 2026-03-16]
CAD/XY motor rear-left mounting.step
68.0 x 76.7 x 56.0 mm

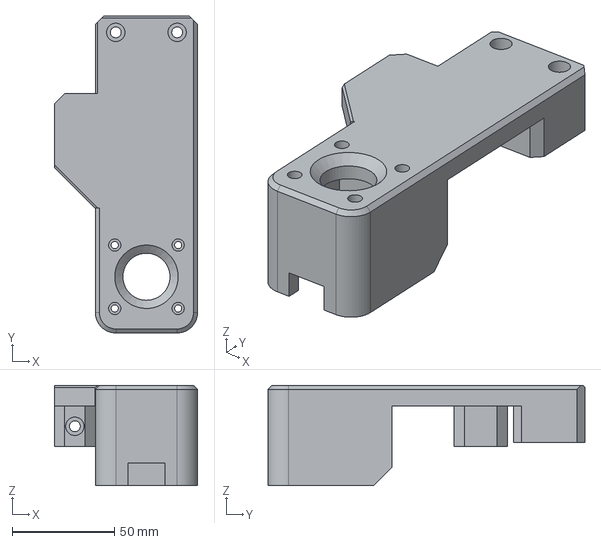
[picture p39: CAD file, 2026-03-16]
CAD/Z motor rear mounting.step
70.0 x 155.0 x 49.0 mm

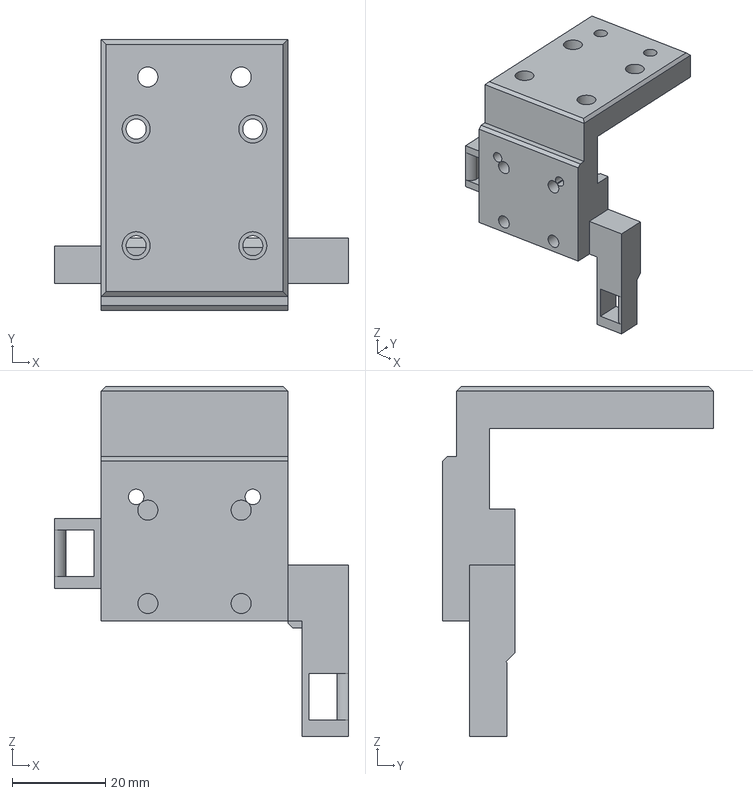
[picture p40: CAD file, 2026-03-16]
CAD/printhead mounting1.step
63.0 x 58.0 x 75.0 mm

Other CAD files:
CAD/heated bed mounting left.step
CAD/gantry mounting left.step

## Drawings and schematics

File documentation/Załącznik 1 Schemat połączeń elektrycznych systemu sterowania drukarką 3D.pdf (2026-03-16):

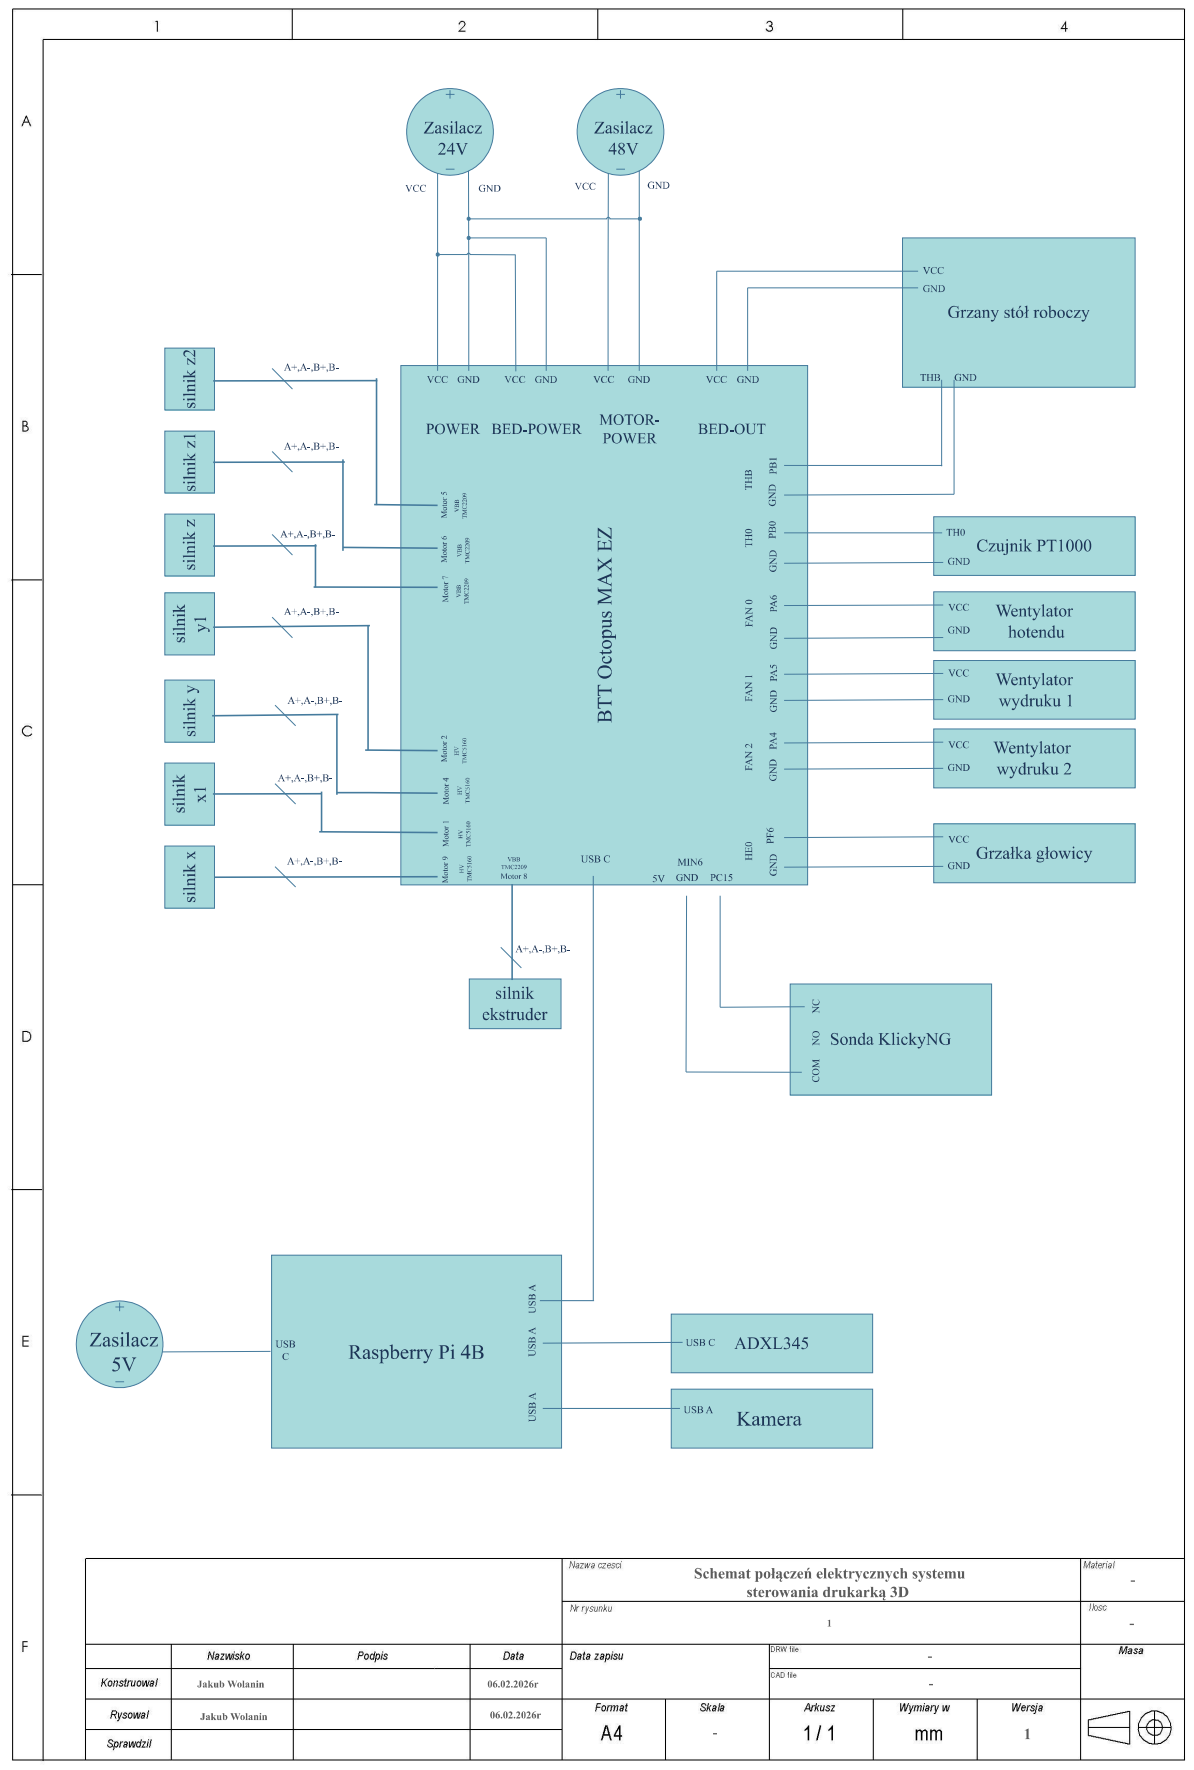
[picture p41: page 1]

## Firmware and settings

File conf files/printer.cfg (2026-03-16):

# This file contains common pin mappings for the BIGTREETECH Octopus Max EZ.
# To use this config, the firmware should be compiled for the
# STM32H723 with a "128KiB bootloader" "25 MHz crystal"
# and "USB (on PA11/PA12)" or "CAN bus (on PD0/PD1)".

# See docs/Config_Reference.md for a description of parameters.


# ========== OBSZAR ROBOCZY DRUKU (dla slicera) ==========
# X: 12 - 312 mm (300mm)
# Y: 12 - 288 mm (276mm)
# position_max to pełny zasięg mechaniczny głowicy (X=318, Y=305)
# ==========================================================

# Motor-1 (M4)
#dir_pin: !PB9
#enable_pin: !PB7
#microsteps: 16
#rotation_distance: 40
#full_steps_per_rotation: 200
#endstop_pin: tmc5160_stepper_x:virtual_endstop
#position_min: -5
#position_endstop: 0
#position_max: 319
#homing_speed: 70
#homing_retract_dist: 0

[stepper_x] #M9
step_pin: PC13     
dir_pin: !PC14    
enable_pin: !PE6    
microsteps: 16
rotation_distance: 40
full_steps_per_rotation: 200
endstop_pin: ^!PF0
position_min: 0
position_endstop: 0
position_max: 319
homing_speed: 30
second_homing_speed: 5
homing_retract_dist: 10

# Motor - 2 (M2)
#stepper_x1]
#step_pin: PE4
#dir_pin: !PE5
#enable_pin: !PE3
#rotation_distance: 40
#microsteps: 16
#full_steps_per_rotation: 200

[stepper_x1] #M1
step_pin: PA8      
dir_pin: !PC7      
enable_pin: !PC9   
rotation_distance: 40
microsteps: 16
full_steps_per_rotation: 200

# Motor-3 (M9)
#[stepper_y]
#step_pin: PA8
#dir_pin: !PC7
#enable_pin: !PC9
#microsteps: 16
#rotation_distance: 40
#full_steps_per_rotation: 200
#endstop_pin: tmc5160_stepper_y1:virtual_endstop
#position_min: -5
#position_endstop: 305
#position_max: 305
#homing_speed: 80
#homing_retract_dist: 0

[stepper_y]
step_pin: PB8      ; Piny z dawnego X
dir_pin: !PB9      ; Bez zmian (zostaje wykrzyknik jaki był w oryginale X)
enable_pin: !PB7   ; Piny z dawnego X
microsteps: 16
rotation_distance: 40
full_steps_per_rotation: 200
endstop_pin: ^!PF3
position_endstop: 265
position_min: 0
position_max: 265
homing_speed: 50
second_homing_speed: 5
homing_retract_dist: 8



# Motor-4 (M1)
#[stepper_y1]
#step_pin: PC13
#dir_pin: !PC14
#enable_pin: !PE6
#rotation_distance: 40
#microsteps: 16
#full_steps_per_rotation: 200

[stepper_y1]
step_pin: PE4      ; Piny z dawnego X1
dir_pin: !PE5      ; Bez zmian
enable_pin: !PE3   ; Piny z dawnego X1
rotation_distance: 40
microsteps: 16
full_steps_per_rotation: 200

# Motor-5
[stepper_z]
step_pin: PB5 
dir_pin: !PB4
enable_pin: !PB6 
microsteps: 32
rotation_distance: 8
endstop_pin: probe:z_virtual_endstop
position_min: -10
position_max: 270
homing_speed: 8.0
second_homing_speed: 3.0
homing_retract_dist: 6.0

# Motor-6
[stepper_z1]
step_pin: PG15
dir_pin: !PB3
enable_pin: !PD5
microsteps: 32
rotation_distance: 8

[stepper_z2]
step_pin:  PD3
dir_pin: !PD2
enable_pin:  !PD4
microsteps: 32
rotation_distance: 8

# Motor-4
# The Octopus only has 4 heater outputs which leaves an extra stepper
# This can be used for a second Z stepper, dual_carriage, extruder co-stepper,
# or other accessory such as an MMU
#[stepper_]
#step_pin: PB8
#dir_pin: PB9
#enable_pin: PB7
#endstop_pin: PF3
#...

# Motor-8
[extruder]
step_pin: PA10
dir_pin: PA9
enable_pin: !PA15
microsteps: 16
rotation_distance: 3.6
nozzle_diameter: 0.400
filament_diameter: 1.750
heater_pin: PF6 # HE0
sensor_pin:  PB0 # T0
sensor_type: PT1000
pullup_resistor: 2200
#control: pid
#pid_Kp: 22.2
#pid_Ki: 1.08
#pid_Kd: 114
min_temp: 0
max_temp: 280

#[filament_switch_sensor material_0]
#switch_pin: PF1

#[filament_switch_sensor material_1]
#switch_pin: PC15

# Motor-7

# Motor-8
#[extruder3]
#step_pin: PA10
#dir_pin: PA9
#enable_pin: !PA15
#heater_pin: PF7 # HE3
#sensor_pin: PA7 # T3
#...

# Motor-9
#[extruder4]
#step_pin: PA8
#dir_pin: PC7
#enable_pin: !PC9
#...

# Motor-10
#[extruder5]
#step_pin: PG6
#dir_pin: PC6
#enable_pin: !PC8
#...

[heater_bed]
heater_pin: PF5
sensor_pin: PB1 # TB
sensor_type: ATC Semitec 104GT-2
#control: watermark
min_temp: 0
max_temp: 130




# ========== WENTYLATORY ==========

[heater_fan hotend_fan]
pin: PA6
heater: extruder
heater_temp: 50.0
fan_speed: 1.0


[multi_pin part_cooling_pins]
pins: PA5, PA4

[fan]
pin: multi_pin:part_cooling_pins



[controller_fan electronics_fan]
pin: PA3
stepper: stepper_x, stepper_y, stepper_z
idle_timeout: 60
fan_speed: 1.0


[mcu]
serial: 

[virtual_sdcard]
path: ~/printer_data/gcodes

[pause_resume]

[display_status]

[gcode_macro PAUSE]
rename_existing: BASE_PAUSE
gcode:
    {% set z = params.Z|default(10)|int %}
    BASE_PAUSE
    G91
    G1 Z{z} F600
    G90
    G1 X10 Y10 F6000

[gcode_macro RESUME]
rename_existing: BASE_RESUME
gcode:
    G91
    G1 Z-10 F600
    G90
    BASE_RESUME

[gcode_macro CANCEL_PRINT]
rename_existing: BASE_CANCEL_PRINT
gcode:
    M104 S0
    M140 S0
    G91
    G1 Z10 F600
    G90
    G1 X10 Y260 F6000
    M84
    BASE_CANCEL_PRINT


[printer]
kinematics: corexy
max_velocity: 500          #
max_accel: 15000         
max_z_velocity: 15
max_z_accel: 300
square_corner_velocity: 8.0 #

########################################
# TMC5160 configuration
########################################

#[tmc5160 stepper_x]
#cs_pin: PG11
#spi_bus: spi4  
#spi_software_sclk_pin: PE12
#spi_software_mosi_pin: PE14
#spi_software_miso_pin: PE13
#sense_resistor: 0.075  
#diag1_pin: ^!PF3      
#run_current: 0.800  
#driver_SGT: 1           
#stealthchop_threshold: 0

[tmc5160 stepper_x] #M1
cs_pin: PG14           
spi_bus: spi4
sense_resistor: 0.075
run_current: 0.100
stealthchop_threshold: 0


#[tmc5160 stepper_x1]
#cs_pin: PG13
#spi_bus: spi4  
#run_current: 0.100  
#stealthchop_threshold: 0

[tmc5160 stepper_x1] #M9
cs_pin: PG8             
spi_bus: spi4
sense_resistor: 0.075   # Dodano dla bezpieczeństwa      
run_current: 0.650
stealthchop_threshold: 0

#[tmc2209 stepper_x1]
#uart_pin: PG13
#interpolate: False
#run_current: 0.100
#sense_resistor: 0.110
#stealthchop_threshold: 0

#[tmc5160 stepper_y]
#cs_pin: PG8
#spi_bus: spi4  
#spi_software_sclk_pin: PE12
#spi_software_mosi_pin: PE14
#spi_software_miso_pin: PE13
#sense_resistor: 0.075   
#run_current: 0.100
#driver_SGT: 1
#stealthchop_threshold: 0

[tmc5160 stepper_y]
cs_pin: PG11            # (Dawny M4)
spi_bus: spi4
run_current: 0.800
stealthchop_threshold: 0

#[tmc2209 stepper_y]
#uart_pin: PG8
#interpolate: False
#run_current: 0.100
#sense_resistor: 0.110
#stealthchop_threshold: 0

#[tmc5160 stepper_y1]
#cs_pin: PG14
#spi_bus: spi4  
#spi_software_sclk_pin: PE12
#spi_software_mosi_pin: PE14
#spi_software_miso_pin: PE13
#diag1_pin: ^!PF0
#sense_resistor: 0.075
#run_current: 0.800  
#driver_SGT: 1
#stealthchop_threshold: 0

[tmc5160 stepper_y1] #M2
cs_pin: PG13            
spi_bus: spi4
run_current: 0.100  
stealthchop_threshold: 0

[tmc2209 stepper_z]
uart_pin: PG10
interpolate: False
run_current: 0.8
sense_resistor: 0.110
stealthchop_threshold: 0

[tmc2209 stepper_z1]
uart_pin: PG9
interpolate: False
run_current: 0.8
sense_resistor: 0.110
stealthchop_threshold: 0


[tmc2209 stepper_z2]
uart_pin:PD7
interpolate: False
run_current: 0.8
sense_resistor: 0.110
stealthchop_threshold: 0

[tmc2209 extruder]
uart_pin: PD6
interpolate: False
run_current: 0.350
sense_resistor: 0.110
stealthchop_threshold: 999999


[board_pins]
aliases:
    # FPC header, Aliases EXP1 & EXP2 for mini12864
    EXP1_1=PG2, EXP1_2=PD15,
    EXP1_3=PD14, EXP1_4=PD13,
    EXP1_5=PD12, EXP1_6=PD11,
    EXP1_7=PD10, EXP1_8=PE15,
    EXP1_9=<GND>, EXP1_10=<5V>,

    # EXP2 header
    EXP2_1=PE13, EXP2_2=PE12,
    EXP2_3=PG5, EXP2_4=PE11,
    EXP2_5=PG4, EXP2_6=PE14,
    EXP2_7=PG3, EXP2_8=<RST>,
    EXP2_9=<GND>, EXP2_10=<NC>

# See the sample-lcd.cfg file for definitions of common LCD displays.

#[bltouch]
#sensor_pin: ^PB15
#control_pin: PB14

# Proximity switch
[probe]
pin: ^PC15
x_offset: 37    
y_offset: -1
#z_offset: 9.7
speed: 6.0
samples: 3
samples_result: median
sample_retract_dist: 3.0
samples_tolerance: 0.025
samples_tolerance_retries: 10
deactivate_on_each_sample: True
#[output_pin ps_on_pin]
#pin: PF13

#[output_pin pf12_pin]
#pin: PF12

#[neopixel my_neopixel_1]
#pin: PE10

#[neopixel my_neopixel_2]
#pin: PE9

#[hall_filament_width_sensor]
#adc1: PC0
#adc2: PF10


[mcu adxl]
serial: /dev/serial/by-id/usb-Klipper_rp2040_50445061287CB91C-if00

[adxl345]
cs_pin: adxl:gpio9
spi_software_sclk_pin: adxl:gpio10
spi_software_mosi_pin: adxl:gpio11
spi_software_miso_pin: adxl:gpio8

[resonance_tester]
accel_chip: adxl345
probe_points:
    150, 150, 20    # Środek stołu

[input_shaper]
# Wartości zostaną uzupełnione po kalibracji
#shaper_freq_x: 50
#shaper_freq_y: 50
#shaper_type: mzv
# ===========================================
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
